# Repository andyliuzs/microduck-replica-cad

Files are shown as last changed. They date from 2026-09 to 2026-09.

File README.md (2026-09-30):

# Microduck 复刻 · SolidWorks 三维图纸与装配说明书

> **可编辑的 SolidWorks 源文件**（不是 STL），外加一份 21 页的装配安装说明书。**两个版本**：
> **v2.1 飞特 HD-1910 版**（2026-09-25，轮辋 + 轮胎合并）和 **v1.1 原版 XL330 版**（2026-09-15，踝 / 小腿 / 脚同步改了）。
> 配套主仓：[**fanhao375/microduck-replica**](https://github.com/fanhao375/microduck-replica) —— 整机复刻、电路板与逆向分析都在那边。

> **模型与打印文件统一在本仓库维护（2026-09-28）。** 主仓已移除旧上游 STL 下载副本。请先选择飞特或 XL330 版本，再核对具体附件；两款舵机的配合件不能混用。

> 📦 **压缩包在 [Releases 页](../../releases)（页面右边栏），不在上面的文件列表里。** 374 MB 的 SolidWorks 不适合塞进 git。
> 🖨️ 飞特打印工程见下方[打印说明](#打印)。仓库内 3MF 是 **2026-09-15 版，尚未包含 v2.1 的 TPU 合体轮胎**；该轮胎变更属于轮滑变体。[MakerWorld 工程](https://makerworld.com.cn/zh/models/2963569-microduck#profileId-3478428)由机械行者Robo 上传，本轮未核验其在线版本。

<div align="center">
  飞特 HD-1910 版装机实物
  <br><sub>2026-09-13 · 飞特 HD-1910 版装出来了，15 颗全在位</sub>
</div>

<div align="center">
  microduck 装配体
  microduck 爆炸图
</div>

---

## 两个版本，选一个下

| | 原版 · XL330 · **v1.1** | 飞特 · HD-1910 · **v2.1** |
|---|---|---|
| **舵机** | Dynamixel XL330-M288 | 飞特 HD-1910-C001 |
| **文件** | 57 个 SolidWorks，无后缀 | 60 个 SolidWorks + 11 个 STEP，`-FT` 后缀 |
| **差别** | — | **舵盘凸出**，8 个配合件改了（[改了什么](#飞特-hd-1910-版改了什么)） |
| **打印** | 从 [v1.1 SolidWorks 源文件](https://github.com/fanhao375/microduck-replica-cad/releases/tag/v1.1) 按零件导出 STL 后切片；本仓暂无该版整套打印工程 | [`打印/` 3MF](打印/) 为 09-15 版，未含 v2.1 合体轮胎；见[版本提示](#打印) |
| **实物** | — | 已装出（上图） |
| **下载** | [`SolidWorks-XL330-v1.1.zip`](https://github.com/fanhao375/microduck-replica-cad/releases/download/v1.1/SolidWorks-XL330-v1.1.zip) 333 MB | [`SolidWorks-FT2026-09-25.zip`](https://github.com/fanhao375/microduck-replica-cad/releases/download/v2.1/SolidWorks-FT2026-09-25.zip) 343 MB |

两版的踝 / 小腿 / 脚在 2026-09-15 同步成了一套设计；装配说明书和组件图两版通用。

---

## 图纸作者：机械行者Robo

**这套三维图纸和安装说明书，全部由「机械行者Robo」建模、整理、编写。**

他还在做装配视频，有装配上的问题去他那儿留言最快：

<table>
<tr>
<td align="center" width="50%">
  小红书 机械行者Robo<br>
  <b>小红书 · 机械行者Robo</b><br>
  <sub>小红书号 270594280</sub>
</td>
<td align="center" width="50%">
  抖音 机械行者Robo<br>
  <b>抖音 · 机械行者Robo</b><br>
  <sub>抖音号 1852366168 —— 「人人可做机器人」</sub>
</td>
</tr>
</table>

> 觉得图纸有用的话，去关注一下他 —— 这套东西建模和整理的工作量不小，而且是免费放出来的。

---

## 下载

| 要什么 | 在哪 |
|---|---|
| **飞特 HD-1910 版源文件**（v2.1 · 60 个 SolidWorks，解压约 358 MB） | 👉 [**下载 `SolidWorks-FT2026-09-25.zip`**](https://github.com/fanhao375/microduck-replica-cad/releases/download/v2.1/SolidWorks-FT2026-09-25.zip) |
| **只要改动件的 STEP**（v2.1 · 11 个） | 👉 [**下载 `STEP-changed-parts-FT-2026-09-30.zip`**](https://github.com/fanhao375/microduck-replica-cad/releases/download/v2.1/STEP-changed-parts-FT-2026-09-30.zip) —— 新增面部零件 FT1（适配瑞莎原版摄像头），不用 SolidWorks 也能开 |
| **原版 XL330 版源文件**（v1.1 · 57 个 SolidWorks，解压 348 MB） | 👉 [**下载 `SolidWorks-XL330-v1.1.zip`**](https://github.com/fanhao375/microduck-replica-cad/releases/download/v1.1/SolidWorks-XL330-v1.1.zip)（[v1.0 旧版](../../releases/tag/v1.0) 仍可下） |
| **装配 BOM**（机械行者Robo 整理，33 个打印件 + 21 个外购件，含材料、数量、单价，**2026-09-29 起所有外购件都带淘宝 / 天猫采购链接**） | [`BOM/装配BOM-机械行者Robo-2026-09-29-带采购链接.xlsx`](BOM/装配BOM-机械行者Robo-2026-09-29-带采购链接.xlsx)，下面有校对过的表 |
| **装配安装说明书**（21 页 PDF） | [`安装说明书/microduck装配安装说明书.pdf`](安装说明书/microduck装配安装说明书.pdf) |
| **组件图 / 爆炸图**（23 张） | [`组件图/`](组件图/) |
| 🖨️ **打印工程文件**（Bambu Studio `.3mf`，4.9 MB，2026-09-15 版） | [`打印/microduck-飞特版-BambuStudio.3mf`](打印/microduck-飞特版-BambuStudio.3mf) —— 5 个盘、52 个对象；**未含 v2.1 合体轮胎**，材料与切片参数见[打印说明](#打印) |
| 🖨️ **MakerWorld 打印入口** | [MakerWorld · microduck 飞特版](https://makerworld.com.cn/zh/models/2963569-microduck#profileId-3478428) —— 使用前核对作者标注的版本与材料，本轮未核验在线更新 |

> **为什么源文件放 Releases 不放 git**：SolidWorks 是二进制格式，git 存它既不能 diff 也不能合并，
> 只会一版版往历史里堆 —— 改三次图仓库就上 1 GB，而且**历史删不掉**。
> 放 Release 附件则不计入仓库体积，更新时发新版即可，clone 这个仓库始终只有几 MB。

---

## 飞特 HD-1910 版改了什么

原版用 Dynamixel XL330，本仓库主仓走飞特 HD-1910（更便宜、力矩大 2.5 倍、电压额定匹配 —— 见[主仓执行器选型](https://github.com/fanhao375/microduck-replica/blob/master/docs/执行器选型.md)）。
**两款舵机外形接近但舵盘不一样：HD-1910 的舵盘是凸出来的，XL330 是凹进去的。** 所有跟舵盘配合的件都得改：

| 改动件 | 为什么 |
|---|---|
| `left_upper_leg` / `right_upper_leg` 左右上腿 | 髋 pitch 和膝的舵盘位 |
| `leg` 小腿 | 膝和踝的舵盘位 |
| `trunk_base` 躯干底座 | 髋 yaw 舵机安装位 |
| `yaw2roll` 偏航转横滚 | 髋 yaw 舵盘 → 髋 roll 舵机 |
| `bearing_roll` 轴承滚轮 | 髋 roll 轴承座 |
| `01-upper_leg_rigidity_plate` 上腿加固板 | 跟上腿一起改 |
| `99-yaw_roll_motion` 偏航横滚运动 | 头部 yaw/roll，`-F` 和 `-FT` 两个变体 |

**文件命名**：所有件带 `-FT` 后缀（FT = 飞特）。没改的件也带 `-FT`，是为了整套装配体引用一致 —— 27 个件跟 v1.0 内容一样，只是改了名。

**多出来的**：`HD-1910-c001-dan / -shuang`（单盘 / 双盘舵机模型）、`舵机比较.SLDASM`（两款舵机并排对比）、`飞特电机资料1/`（飞特给的 STEP / DWG / 规格图）。

⚠️ 装配说明书 PDF 和组件图**还是 v1.0 的**，装配顺序和步骤不变，只是舵机换了。

---

## 飞特 v2.1 改了什么（2026-09-25）

- **`rim_轮辋` 和 `tire_轮胎` 合并为 `合体轮胎`**：两个独立件组装困难，删除后合成一个「合体轮胎」，材料 **TPU**。
- 全套 SolidWorks 现在是 **60 个**（17 装配体 + 43 零件）；改动件 STEP 增到 **10 个**（新增 `合体轮胎.STEP`）。

---

## 面部零件适配瑞莎原版摄像头（2026-09-30）

- **`face_part_面部零件` 新增 `-FT1` 变体**：把摄像头安装孔距改成能直接装**瑞莎（Radxa）原版摄像头**。
- 改动件 STEP 包相应新增 **`face_part_面部零件-FT1适配瑞莎原版摄像头 改了孔距.STEP`**，由 10 个增到 **11 个**。

---

## XL330 原版 v1.1 改了什么（2026-09-15）

飞特版改踝、小腿、脚那一片时顺手把原版也改了，两版这一区域现在是同一套设计：

```
改了   05_左小腿 · 06_左踝脚 · 14_右小腿 · 15_右踝脚 · 10_头部总成
       ankle_left 脚踝左 · foot_left 左脚 · leg 腿部
新增   deep groove ball bearings gb（轴承模型）
改名   00-microduck装配体 → 00-microduck装配体 XL330-288舵机版本
       ankle_right_脚踝右 → ankle_right脚踝右
```

46 个件跟 v1.0 一样。

---

## 装配 BOM

> 工作簿已更新到 **2026-09-29**：轮辋 + 轮胎合并为**合体轮胎**（打印件 33 项），外购件扩到 **21 项**，并且**所有外购件都加了淘宝 / 天猫采购链接**（2026-09-16 版只有轴承和螺丝有）。

[`BOM/装配BOM-机械行者Robo-2026-09-29-带采购链接.xlsx`](BOM/装配BOM-机械行者Robo-2026-09-29-带采购链接.xlsx) 是机械行者Robo 按装配体整理的。2026-09-29 版把外购件补齐成完整清单（主控 Radxa Zero 3W、TF 卡、飞特 URT2 调试板、电池座、ToF 等），并给每一项加上实际下单的淘宝 / 天猫链接（打板件指到主仓 github，拼团的直接标拼团）。电子件型号按主仓查证过的事实排（电池 NP-F550、舵机 15、`imu_to_dxl` 1），下面这张表照它排。有几处跟表不同：

| 表里 | 这里 | 依据 |
|---|---|---|
| 合体轮胎 / 滚轮叶片 | 标为**轮滑变体，走路不用** | 上游 `变体-轮滑/`，只有做轮滑功能才打 |
| 合体轮胎材料写 PLA | 实际应打 **TPU** | v2.1 合体轮胎是 TPU 软料，见[飞特 v2.1 改了什么](#飞特-v21-改了什么2026-09-25) |

### 一、3D 打印件（33 项）

| # | 零件 | 文件 | 材料 | 数量 | 备注 |
|---|---|---|---|---|---|
| 1 | 头部上壳 | `top_head_shell` | PLA | 1 | |
| 2 | 头部下壳 | `bottom_head_shell` | PLA | 1 | |
| 3 | 面部零件 | `face_part` | PLA | 1 | |
| 4 | 下巴 | `jaw` | PLA | 1 | |
| 5 | 软下巴 | `jaw_soft` | **TPU** | 1 | 软性件 |
| 6 | 软嘴顶部 | `soft_mouth_top` | **TPU** | 1 | 软性件 |
| 7 | 眼睛 | `noenoeil` | PLA | 1 | |
| 8 | 颈部 | `neck` | PLA | 2 | 可换铝合金增强 |
| 9 | 颈部俯仰 | `neck_pitch` | PLA | 1 | |
| 10 | 躯干底座 | `trunk_base` | PLA | 1 | 可换铝合金增强 |
| 11 | 左壳 | `left_shell` | PLA | 1 | |
| 12 | 右壳 | `right_shell` | PLA | 1 | |
| 13 | 髋部左 | `hip_l` | PLA | 2 | |
| 14 | 偏航转横滚 | `yaw2roll` | PLA | 1 | |
| 15 | 偏航横滚运动 | `yaw_roll_motion` | PLA | 1 | |
| 16 | 腿部 | `leg` | PLA | 2 | |
| 17 | 左上腿 | `left_upper_leg` | PLA | 1 | |
| 18 | 右上腿 | `right_upper_leg` | PLA | 1 | |
| 19 | 上腿加固板 | `upper_leg_rigidity_plate` | PLA | 2 | 可换铝合金增强 |
| 20 | 左脚 | `foot_left` | PLA | 1 | |
| 21 | 右脚 | `foot_right` | PLA | 1 | |
| 22 | 左脚底 | `sole_left` | PLA | 1 | |
| 23 | 右脚底 | `sole_right` | PLA | 1 | |
| 24 | 脚踝左 | `ankle_left` | PLA | 1 | |
| 25 | 脚踝右 | `ankle_right` | PLA | 1 | |
| 26 | 脚踝左 V1 | `ankle_l_v1` | PLA | 1 | 备选，与 24 二选一 |
| 27 | 脚踝右 V1 | `ankle_r_v1` | PLA | 1 | 备选，与 25 二选一 |
| 28 | 合体轮胎 | `合体轮胎` | **TPU** | 4 | **轮滑变体，走路不用**；v2.1 把轮辋 + 轮胎合并 |
| 29 | 滚轮叶片 | `roller_blade` | PLA | 2 | **轮滑变体，走路不用** |
| 30 | 电机支架 | `motor_support` | PLA | 1 | |
| 31 | 电源支架 | `power_support` | PLA | 1 | |
| 32 | 香蕉形 PCB 锁扣 | `banana_pcb_locker` | PLA | 1 | |
| 33 | 轴承滚轮 | `bearing_roll` | PLA | 2 | 可换铝合金增强 |

### 二、外购件（21 项）

| # | 件 | 数量 | 单价(元) | 备注 / 采购链接 |
|---|---|---|---|---|
| 34 | Radxa Zero 3W 主控 | 1 | 309 | [淘宝 763812025816](https://item.taobao.com/item.htm?id=763812025816) |
| 35 | 64GB TF 卡 | 1 | 60 | |
| 36 | RPI Robot HAT 电路板 | 1 | — | 官方开源，嘉立创打样；或[不打 HAT 飞线](https://github.com/fanhao375/microduck-replica/blob/master/docs/不打HAT.md) |
| 37 | imu_to_dxl 电路板 | 1 | — | 主仓自绘，[hardware/imu_to_dxl](https://github.com/fanhao375/microduck-replica/tree/master/hardware/imu_to_dxl) |
| 38 | 飞特 HD1901M 舵机 | 15 | — | 可[拼团](https://github.com/fanhao375/microduck-replica)；主仓写 **HD-1910-C001** |
| 39 | 飞特舵机 URT2 调试板 | 1 | 45 | [淘宝 575365901461](https://item.taobao.com/item.htm?id=575365901461&skuId=5435424470243) |
| 40 | NP-F550 电池 | 1 | 17 | 2S；[天猫 658975825526](https://detail.tmall.com/item.htm?id=658975825526&skuId=4925738602652) |
| 41 | 电池座 | 1 | 83 | [天猫 714898043960](https://detail.tmall.com/item.htm?id=714898043960&skuId=5173334659309) |
| 42 | 2.5mm 香蕉插头 PCB 铜镀金 | 2 | 1.6 | [淘宝 1066300439603](https://item.taobao.com/item.htm?id=1066300439603&skuId=6116801109787) |
| 43 | banana PCB | 1 | — | 嘉立创 |
| 44 | IMX219 摄像头模块 | 1 | 46.8 | [天猫 775872575316](https://detail.tmall.com/item.htm?id=775872575316) |
| 45 | VL53L8CX ToF 模块 | 1 | 49.5 | [淘宝 737603917521](https://item.taobao.com/item.htm?id=737603917521&skuId=5090650052053) |
| 46 | 扬声器 | 1 | 3.8 | 走 HAT 音频才要；[淘宝 902489608878](https://item.taobao.com/item.htm?id=902489608878&skuId=5925223242747) |
| 47 | 轴承 10×15×3 | 3 | 2.8 | [淘宝 670727787832](https://item.taobao.com/item.htm?id=670727787832) |
| 48 | 轴承 16×22×4 | 11 | 3.5 | [淘宝 539024647147](https://item.taobao.com/item.htm?id=539024647147&skuId=5716548727712) |
| 49 | 轴承 6×12×3 | 4 | 0.88 | 轮滑变体用，走路不用买；[淘宝 963037239628](https://item.taobao.com/item.htm?id=963037239628&skuId=6068333830994) |
| 50 | 螺丝 M2×5 | 1 包 | 3.05 | [天猫 637524754721](https://detail.tmall.com/item.htm?id=637524754721&skuId=5802482233046) |
| 51 | 螺丝 M2×6 | 1 包 | 4.05 | 同一家：[天猫 637524754721](https://detail.tmall.com/item.htm?id=637524754721&skuId=5802482233047) |
| 52 | 螺丝 M2.5×6 | 1 包 | 3.93 | 同一家：[天猫 637524754721](https://detail.tmall.com/item.htm?id=637524754721&skuId=6180818899668) |
| 53 | 螺丝 M2.5×8 | 1 包 | 2.08 | 同一家：[天猫 637524754721](https://detail.tmall.com/item.htm?id=637524754721&skuId=4572694449141) |
| 54 | 乐泰螺纹胶 243 | 1 | 9 | [淘宝 1056442610986](https://item.taobao.com/item.htm?id=1056442610986&skuId=6099342537028) |

> 每种螺丝多少颗见[主仓紧固件反推](https://github.com/fanhao375/microduck-replica/blob/master/docs/紧固件反推.md)。BOM 合计 **约 828 元**（不含 15 个舵机、HAT 板和 IMU 板；单价为机械行者Robo 下单时价）。

---

## 项目成本与开源倡议

> 🦆 **人人都可以拥有属于自己的 MicroDuck！**

**💰 项目成本**：除 15 个舵机、HAT 板和 IMU 板外，其余硬件成本约为 **828 元**。舵机、HAT 板和 IMU 板可以通过 [GitHub 项目](https://github.com/fanhao375/microduck-replica) 参与拼团，也可以根据需求在嘉立创、淘宝等平台自行购买。

后续还会陆续开源安装教程、调试教程，帮助大家更方便地完成 MicroDuck 的组装与调试。

**🤖 为什么要开源？** 希望让更多人能以更低的成本接触和学习具身智能、机器人控制与强化学习，动手实践、从零探索。如果这个项目对你有帮助，点个赞就是对我们最大的支持 ❤️，也欢迎点个 Star ⭐！

> 🔗 GitHub：https://github.com/fanhao375/microduck-replica
> 📕 小红书：机械行者 · 🎵 抖音：机械行者Robo · B站：机械行者Robo

---

## 打印

**[`打印/microduck-飞特版-BambuStudio.3mf`](打印/microduck-飞特版-BambuStudio.3mf)** —— 机械行者Robo 排好盘的 Bambu Studio 工程，版本为 **2026-09-15**。

**这不是完整 v2.1 打印包。** 已核对工程内仍有独立轮辋 4 个、轮胎 4 个，没有 v2.1 合体轮胎；若制作新版轮滑变体，请从 [v2.1 源文件](https://github.com/fanhao375/microduck-replica-cad/releases/tag/v2.1) 导出合体轮胎，按 TPU 切片，避免与旧轮辋/轮胎重复打印。[MakerWorld 在线工程](https://makerworld.com.cn/zh/models/2963569-microduck#profileId-3478428)是否同步本轮未验证。此处只更新入口与版本说明，没有修改 3MF 或 CAD 模型。

| 项 | 值 |
|---|---|
| 打印机 | Bambu Lab **P2S**，0.4 喷嘴 |
| 耗材 | PLA Basic |
| 层高 | 0.2 mm |
| 盘数 | **5 盘**，52 个对象 —— 09-15 工程中的对象，非 v2.1 完整清单 |

<table>
<tr>
<td align="center"><br><sub>盘 1</sub></td>
<td align="center"><br><sub>盘 2</sub></td>
<td align="center"><br><sub>盘 3</sub></td>
<td align="center"><br><sub>盘 4</sub></td>
<td align="center"><br><sub>盘 5</sub></td>
</tr>
</table>

**怎么用**：先核对舵机版本、所需零件与材料，再用 Bambu Studio 打开工程、检查排盘并切片。软下巴、软嘴顶部与轮胎等柔性件应按 BOM 使用 TPU，不能统一按默认 PLA 打印。使用其他打印机时，应确认切片软件支持导入该 3MF，并按自己的机器重设打印参数。

耗材、螺丝、热熔螺母的采购在[主仓机械采购清单](https://github.com/fanhao375/microduck-replica/blob/master/docs/机械采购清单.md)。

---

## 组件清单（15 个）

| 序号 | 组件 | 英文 | 位置 / 功能 |
|---|---|---|---|
| 01 | 躯干主体 | Torso | 机身主体，**全部组件的装配基准件**，承载左/右腿、颈部与控制器 |
| 02 | 左髋 | Left Hip | 左腿根部髋关节（Pitch），腿部前后摆动 |
| 03 | 左髋 Roll | Left Hip Roll | 左腿髋部横滚关节，腿部侧向摆动 |
| 04 | 左大腿 | Left Thigh | 连接髋关节与小腿 |
| 05 | 左小腿 | Left Calf | 连接大腿与踝关节 |
| 06 | 左踝脚 | Left Ankle & Foot | 踝关节及脚部，足部转动与支撑 |
| 07 | 颈根 | Neck Base | 颈部与机身连接处的旋转底座（Yaw） |
| 08 | 颈俯仰 | Neck Pitch | 颈部俯仰摆动关节 |
| 09 | 头 Yaw / Roll | Head Yaw / Roll | 头部水平摆动与横滚关节 |
| 10 | 头部总成 | Head Assembly | 头部完整组件，含外壳、摄像头等 |
| 11 | 右髋 | Right Hip | 与 02 镜像对称 |
| 12 | 右髋 Roll | Right Hip Roll | 与 03 镜像对称 |
| 13 | 右大腿 | Right Thigh | 与 04 镜像对称 |
| 14 | 右小腿 | Right Calf | 与 05 镜像对称 |
| 15 | 右踝脚 | Right Ankle & Foot | 与 06 镜像对称 |

## 装配顺序

**按编号 01 → 15 依次装，就是推荐的整机装配顺序：**

```
1.  01           躯干主体 —— 作为整机基准先行固定
2.  02 → 06      左腿   左髋 → 左髋Roll → 左大腿 → 左小腿 → 左踝脚
3.  07 → 10      颈头   颈根 → 颈俯仰 → 头Yaw/Roll → 头部总成
4.  11 → 15      右腿   右髋 → 右髋Roll → 右大腿 → 右小腿 → 右踝脚
```

**每一步的详细步骤、配图和注意事项，见** [装配安装说明书 PDF](安装说明书/microduck装配安装说明书.pdf)。

---

## 组件图

<table>
<tr>
<td align="center"><br><sub><b>01</b> 躯干主体</sub></td>
<td align="center"><br><sub><b>02</b> 左髋</sub></td>
<td align="center"><br><sub><b>03</b> 左髋 Roll</sub></td>
<td align="center"><br><sub><b>04</b> 左大腿</sub></td>
</tr>
<tr>
<td align="center"><br><sub><b>05</b> 左小腿</sub></td>
<td align="center"><br><sub><b>06</b> 左踝脚</sub></td>
<td align="center"><br><sub><b>07</b> 颈根</sub></td>
<td align="center"><br><sub><b>08</b> 颈俯仰</sub></td>
</tr>
<tr>
<td align="center"><br><sub><b>09</b> 头 Yaw/Roll</sub></td>
<td align="center"><br><sub><b>10</b> 头部总成</sub></td>
<td align="center"><br><sub><b>11</b> 右髋</sub></td>
<td align="center"><br><sub><b>12</b> 右髋 Roll</sub></td>
</tr>
<tr>
<td align="center"><br><sub><b>13</b> 右大腿</sub></td>
<td align="center"><br><sub><b>14</b> 右小腿</sub></td>
<td align="center"><br><sub><b>15</b> 右踝脚</sub></td>
<td align="center"><br><sub>头部总成（爆炸）</sub></td>
</tr>
</table>

<div align="center">
  零件总览<br>
  <sub>全部零件总览</sub>
</div>

---

## 文件清单

### 装配体（16 个 `.SLDASM`）

`00-microduck装配体` 是总装，下面 15 个是分组件：

```
00-microduck装配体      70.3 MB      08_颈俯仰               0.3 MB
01_躯干主体             20.5 MB      09_头yaw-roll          0.7 MB
02_左髋yaw-roll         2.5 MB      10_头部总成             22.2 MB
03_左髋roll             3.8 MB      11_右髋yaw-roll         2.5 MB
04_左大腿               1.9 MB      12_右髋roll             3.8 MB
05_左小腿               1.9 MB      13_右大腿               2.0 MB
06_左踝脚               9.3 MB      14_右小腿               1.8 MB
07_颈根                 0.1 MB      15_右踝脚               9.3 MB
```

### 零件（40 个 `.SLDPRT`）

| 类别 | 零件 |
|---|---|
| **躯干 / 外壳** | `trunk_base_躯干底座` · `left_shell_左壳` · `right_shell_右壳` · `power_support_电源支架` · `banana_pcb_locker_香蕉形PCB锁扣` |
| **腿** | `leg_腿部` · `left_upper_leg_左上腿` · `right_upper_leg_右上腿` · `hip_l_髋部左` · `yaw2roll_偏航转横滚` · `yaw_roll_motion_偏航横滚运动` · `01-upper_leg_rigidity_plate_上腿加固板` |
| **踝 / 脚** | `ankle_left_脚踝左` · `ankle_right_脚踝右` · `foot_left_左脚` · `foot_right_右脚` · `sole_left_左脚底` · `sole_right_右脚底` |
| **颈 / 头** | `neck_颈部` · `neck_pitch_颈部俯仰` · `top_head_shell_头部上壳` · `bottom_head_shell_头部下壳` · `face_part_面部零件` · `jaw_下巴` · `jaw_soft_软下巴` · `soft_mouth_top_软嘴顶部` · `noenoeil_眼睛` |
| **摄像头** | `m12_lens_holder_M12镜头座` · `lens_镜头` |
| **电路板** | `3D_PCB1_2026-09-08`（imu_to_dxl，2026-09-08 版）· `elec_rpi_robot_hat_pcb_树莓派机器人HAT电路板` · `pcb__raspberry_pi_zero_2_w_树莓派Zero2W电路板` |
| **标准件 / 外购** | `舵机xl330-288` · `xl330-m288-t1` · `xl330-m288-t2` · `轴承16×22×4` · `bearing_roll_轴承滚轮` · `M2铜柱` · `motor_support_电机支架` · `np_f970_NPF970电池` |

### 两处命名要留意

- **`np_f970_NPF970电池`** —— 文件名沿用了上游的 `np_f970`，但**实物是 NP-F550**。
  主仓实测上游网格包围盒为 **70.8 × 38.6 × 20.6 mm**，正是 F550/F570 的尺寸；真 NP-F970 厚约 60 mm，
  **买错装不进去，而且 300 g 会吃掉整机预算的三分之一**。详见
  [主仓 BOM 的电池型号勘误](https://github.com/fanhao375/microduck-replica/blob/master/BOM.md)。
- **`pcb__raspberry_pi_zero_2_w`** —— 同样是上游的占位命名，**实机主控是 Radxa Zero 3W**（RK3566），
  只是外形同为 Pi Zero。见[主仓的硬件方案逆向](https://github.com/fanhao375/microduck-replica/blob/master/docs/硬件方案逆向.md)。

---

## 通用注意事项（摘自说明书）

- 装配前对照 BOM 清点零件数量与规格，确认 **M2 / M2.5** 螺丝与紧固件齐全
- **舵机类关节件：装配前先通电归中位再锁紧**，避免行程偏移
- 螺丝**对角分步预紧**，避免单边受力导致零件变形；塑料件切勿过度锁紧
- **左右对称件（髋 / 大腿 / 小腿 / 踝脚）务必区分左右**，切勿装反
- 线缆统一固定、预留关节活动余量，严禁压线、夹线、缠绕
- 每完成一个活动关节，转动测试一次，检查是否干涉、卡滞、异响
- 首次通电前检查所有电气连接、绝缘与极性

**推荐工具**：十字/内六角螺丝刀 · 镊子 · 螺纹胶 · 舵机中位调试工具或控制板。

---

## 声明与许可

> ⚠️ **这是第三方复刻件，不是官方设计。** 与 Pollen Robotics 无隶属关系，未获其背书。

本套图纸依据 [`pollen-robotics/microduck_rl`](https://github.com/pollen-robotics/microduck_rl) 公开发布的
STL 网格重建为可编辑的 SolidWorks 参数模型。上游 3D 模型许可为 **CC BY-NC-SA**，
因此本仓库的图纸作为衍生作品同样以 **[CC BY-NC-SA 4.0](https://creativecommons.org/licenses/by-nc-sa/4.0/deed.zh)** 发布：
**署名 · 非商业性使用 · 相同方式共享**。

- **图纸与说明书著作权归「机械行者Robo」**，转载与二次分发请保留署名
- 文档文字部分同样按 CC BY-NC-SA 4.0 发布
- Microduck 是 Pollen Robotics 的商业产品，本仓库不提供任何官方支持

**发现问题**请开 [issue](../../issues)，或到上面两个账号留言。

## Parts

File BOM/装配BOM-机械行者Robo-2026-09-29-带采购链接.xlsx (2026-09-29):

序号 | 类别 | 名称 | 原文件名 | 材料 |  | 数量 | 单价 | 总格 | 网址
一、3D打印件（需打印）
1 | 3D打印件 | 头部上壳 | top_head_shell_头部上壳.stp | PLA |  | 1 |  | 139 | https://item.taobao.com/item.htm?from=cart&id=1083122166800&skuId=6306393642451&upStreamPrice=13900
2 | 3D打印件 | 头部下壳 | bottom_head_shell_头部下壳.stp | PLA |  | 1
3 | 3D打印件 | 面部零件 | face_part_面部零件.stp | PLA |  | 1
4 | 3D打印件 | 下巴 | jaw_下巴.stp | PLA |  | 1
5 | 3D打印件 | 软下巴 | jaw_soft_软下巴.stp | PLA | 建议改用TPU软料 | 1
6 | 3D打印件 | 软嘴顶部 | soft_mouth_top_软嘴顶部.stp | PLA | 建议改用TPU软料 | 1
7 | 3D打印件 | 眼睛 | noenoeil_眼睛.stp | PLA |  | 1
8 | 3D打印件 | 颈部 | neck_颈部.stp | PLA | 建议铝合金 | 2
9 | 3D打印件 | 颈部俯仰 | neck_pitch_颈部俯仰.stp | PLA |  | 1
10 | 3D打印件 | 躯干底座 | trunk_base_躯干底座.stp | PLA | 建议铝合金 | 1
11 | 3D打印件 | 左壳 | left_shell_左壳.stp | PLA |  | 1
12 | 3D打印件 | 右壳 | right_shell_右壳.stp | PLA |  | 1
13 | 3D打印件 | 髋部左 | hip_l_髋部左.stp | PLA |  | 2
14 | 3D打印件 | 偏航转横滚 | yaw2roll_偏航转横滚.stp | PLA |  | 1
15 | 3D打印件 | 偏航横滚运动 | yaw_roll_motion_偏航横滚运动.stp | PLA |  | 1
16 | 3D打印件 | 腿部 | leg_腿部.stp | PLA |  | 2
17 | 3D打印件 | 左上腿 | left_upper_leg_左上腿.stp | PLA |  | 1
18 | 3D打印件 | 右上腿 | right_upper_leg_右上腿.stp | PLA |  | 1
19 | 3D打印件 | 上腿加固板 | upper_leg_rigidity_plate_上腿加固板.stp | PLA | 建议铝合金 | 2
20 | 3D打印件 | 左脚 | foot_left_左脚.stp | PLA |  | 1
21 | 3D打印件 | 右脚 | foot_right_右脚.stp | PLA |  | 1
22 | 3D打印件 | 左脚底 | sole_left_左脚底.stp | PLA |  | 1
23 | 3D打印件 | 右脚底 | sole_right_右脚底.stp | PLA |  | 1
24 | 3D打印件 | 脚踝左 | ankle_left_脚踝左.stp | PLA |  | 1
25 | 3D打印件 | 脚踝右 | ankle_right_脚踝右.stp | PLA |  | 1
26 | 3D打印件 | 脚踝左(V1备选) | ankle_l_v1_脚踝左V1.stp | PLA |  | 1
27 | 3D打印件 | 脚踝右(V1备选) | ankle_r_v1_脚踝右V1.stp | PLA |  | 1
28 | 3D打印件 | 合体轮胎 | 合体轮胎.stp | PLA |  | 4
29 | 3D打印件 | 滚轮叶片 | roller_blade_滚轮叶片.stp | PLA |  | 2
30 | 3D打印件 | 电机支架 | motor_support_电机支架.stp | PLA |  | 1
31 | 3D打印件 | 电源支架 | power_support_电源支架.stp | PLA |  | 1
32 | 3D打印件 | 香蕉形PCB锁扣 | banana_pcb_locker_香蕉形PCB锁扣.stp | PLA |  | 1
33 | 3D打印件 | 轴承滚轮 | bearing_roll_轴承滚轮.stp | PLA | 建议铝合金 | 2
二、外购标准件（无需打印） |  |  |  |  |  |  |  | 0 | 网址
1 | 外购件 | Radxa Zero 3W 主控板 |  | 电子件 |  | 1 | 309 | 309 | https://item.taobao.com/item.htm?id=763812025816&last_time=1790655696&upStreamPrice=88800
2 | 外购件 | 64GB TF 卡 |  | 电子件 |  | 1 | 60 | 60
3 | 外购件 | 树莓派机器人HAT电路板 |  | 电子件 | 可拼团 github | 1 | / | 0 | https://github.com/fanhao375/microduck-replica
4 | 外购件 | imu_to_dxl电路板 |  | 电子件 | 可拼团github | 1 | / | 0 | https://github.com/fanhao375/microduck-replica
5 | 外购件 | 飞特HD1901M舵机 |  | 电子件 | 可拼团github | 15 | / | 0 | https://github.com/fanhao375/microduck-replica
6 | 外购件 | 飞特舵机URT2调试板 |  | 电子件 |  | 1 | 45 | 45 | https://item.taobao.com/item.htm?id=575365901461&xxc=shop&from=cart&skuId=5435424470243
7 | 外购件 | NP-F550电池 |  | 电子件 |  | 1 | 17 | 17 | https://detail.tmall.com/item.htm?id=658975825526&skuId=4925738602652
8 | 外购件 | 电池座 |  | 电子件 |  | 1 | 83 | 83 | https://detail.tmall.com/item.htm?id=714898043960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
9 | 外购件 | 2.5mm香蕉插头PCB铜镀金 |  | 电子件 |  | 2 | 1.6 | 3.2 | https://item.taobao.com/item.htm?from=cart&id=1066300439603&skuId=6116801109787&upStreamPrice=160
10 | 外购件 | banana PCB |  | 电子件 |  | 1 | / | 0 | 嘉立创
11 | 外购件 | IMX219摄像头模块 |  | 光学件 |  | 1 | 46.8 | 46.8 | https://detail.tmall.com/item.htm?id=775872575316
12 | 外购件 | VL53L8CX ToF 模块 |  | 电子件 |  | 1 | 49.5 | 49.5 | https://item.taobao.com/item.htm?from=cart&id=737603917521&skuId=5090650052053&upStreamPrice=4950
13 | 外购件 | 扬声器 |  | 电子件 |  | 1 | 3.8 | 3.8 | https://item.taobao.com/item.htm?ali_trackid=318_1fb351596f290624d1f838f6933a4bf9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
14 | 外购件 | 轴承 10×15×3 |  | 标准件 |  | 3 | 2.8 | 8.4 | https://item.taobao.com/item.htm?id=670727787832
15 | 外购件 | 轴承 16×22×4 |  | 标准件 |  | 11 | 3.5 | 38.5 | https://item.taobao.com/item.htm?id=539024647147&skuId=5716548727712
16 | 外购件 | 轴承 6×12×3 | 轮滑鞋用轴承 | 标准件 |  | 4 | 0.88 | 3.52 | https://item.taobao.com/item.htm?id=963037239628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
17 | 外购件 | 螺丝M2×5 |  | 标准件 |  | 1包 | 3.05 | 3.05 | https://detail.tmall.com/item.htm?ali_trackid=318_52a09f69533ca8994dc6d0b507aea17b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
18 | 外购件 | 螺丝M2×6 |  | 标准件 |  | 1包 | 4.05 | 4.05 | https://detail.tmall.com/item.htm?ali_trackid=318_52a09f69533ca8994dc6d0b507aea17b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
19 | 外购件 | 螺丝M2.5×6 |  | 标准件 |  | 1包 | 3.93 | 3.93 | https://detail.tmall.com/item.htm?ali_trackid=318_52a09f69533ca8994dc6d0b507aea17b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
20 | 外购件 | 螺丝M2.5×8 |  | 标准件 |  | 1包 | 2.08 | 2.08 | https://detail.tmall.com/item.htm?ali_trackid=318_52a09f69533ca8994dc6d0b507aea17b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
21 | 外购件 | 乐泰螺纹胶243 |  | 标准件 |  | 1 | 9 | 9 | https://item.taobao.com/item.htm?id=1056442610986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
合计：3D打印件 33 项 / 外购件 21项 |  |  |  |  |  |  |  | 828.83
说明： 🦆 人人都可以拥有属于自己的 MicroDuck！ 💰 项目成本说明 除 15 个舵机、HAT 板和 IMU 板 外，其余硬件成本约为 828 元。 15 个舵机、HAT 板和 IMU 板 可以通过 GitHub 项目参与拼团，也可以根据需求在 嘉立创、淘宝 等平台自行购买。 后续我们还会陆续开源 安装教程、调试教程，帮助大家更方便地完成 MicroDuck 的组装与调试。 🤖 为什么要开源？ 我们希望让更多人能够以更低的成本接触和学习 具身智能、机器人控制与强化学习。 人人都有属于自己的一只鸭子。 通过开源，我们希望和大家一起打造一个更加开放、友好的学习环境，让更多人能够动手实践，从零开始探索具身智能。 如果这个项目对你有所帮助，点个赞就是对我们最大的支持 ❤️ 也欢迎大家关注我们的 GitHub，帮忙点个 Star ⭐！ 🔗 GitHub： https://github.com/fanhao375/microduck-replica 📕 小红书：机械行者 🎵 抖音：机械行者Robo B站：机械行者Robo

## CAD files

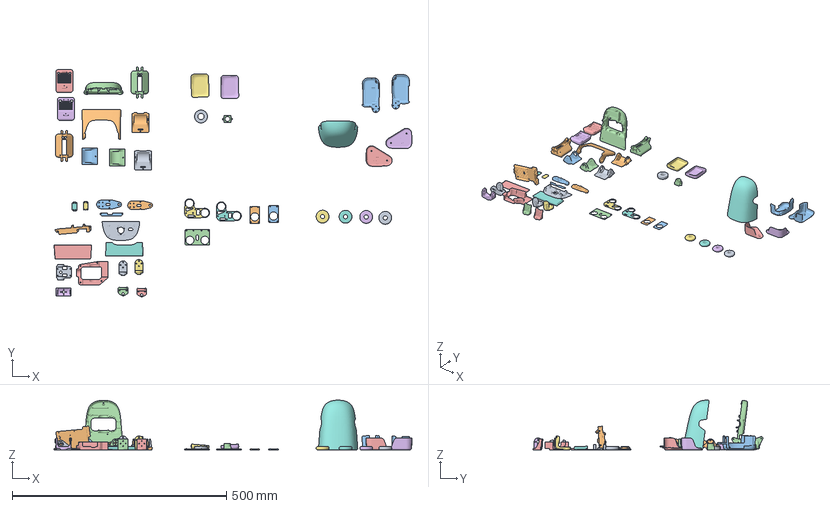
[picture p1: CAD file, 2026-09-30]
打印/microduck-飞特版-BambuStudio2026-09-30.3mf
835.9 x 536.9 x 116.0 mm
ankle_l_v1_脚踝左V1.stl
ankle_r_v1_脚踝右V1.stl
banana_pcb_locker_香蕉形PCB锁扣.stl
bottom_head_shell_头部下壳.stl
foot_left_左脚.stl
foot_right_右脚.stl
hip_l_髋部左.stl x 2
jaw_soft_软下巴.stl
jaw_下巴.stl
left_shell_左壳.stl
m12_lens_holder_M12镜头座.stl
motor_support_电机支架.stl
neck_pitch_颈部俯仰.stl
neck_颈部.stl x 2
noenoeil_眼睛.stl
power_support_电源支架.stl
right_shell_右壳.stl
roller_blade_滚轮叶片.stl x 2
soft_mouth_top_软嘴顶部.stl
sole_left_左脚底.stl
sole_right_右脚底.stl
top_head_shell_头部上壳.stl
face_part_面部零件.stp
ankle_right脚踝右.STEP
ankle_left_脚踝左.STEP
right_upper_leg_右上腿-FT.STEP
left_upper_leg_左上腿-FT.STEP
01-upper_leg_rigidity_plate_上腿加固板-FT.STEP x 2
99-yaw_roll_motion_偏航横滚运动-F.STEP
leg_腿部-FT.STEP x 2
trunk_base_躯干底座.stl

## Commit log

2026-09-25 飞特版 v2.1：轮辋+轮胎合并为合体轮胎（TPU），README 链接与说明同步更新
2026-09-28 Clarify centralized model downloads and print project versions
2026-09-29 装配BOM更新至09-29版（带采购链接），替换09-16版
    [装配BOM-机械行者Robo-2026-09-16-带采购链接.xlsx, 装配BOM-机械行者Robo-2026-09-29-带采购链接.xlsx]
2026-09-30 README 同步 09-29 装配 BOM：33 打印件 + 21 外购件（带采购链接），新增项目成本与开源倡议
2026-09-30 飞特版：面部零件 face_part 出 -FT1 变体，适配瑞莎原版摄像头（改孔距），改动件 STEP 增到 11 个
2026-09-30 README 对照表：飞特版改动件 STEP 由 10 个改为 11 个（含面部零件 FT1）
2026-09-30 飞特版打印工程更新至 09-30 版，替换旧版 3mf
    [microduck-飞特版-BambuStudio.3mf, microduck-飞特版-BambuStudio2026-09-30.3mf]
2026-10-12 README：加 B 站装配视频合集（分集目录）、B 站二维码，三个平台的账号都加上可点链接
2026-10-12 README：主控改为推荐 1G/2G 无 eMMC 版 + TF 卡，只走官方渠道
2026-10-20 飞特版 v2.2：头部上壳加散热孔，左右上腿减小间隙，README 链接与说明同步更新
2026-10-20 更新 BOM 和飞特版打印工程至 2026-10-20 版
    BOM 更新：
    - 增加防滑垫
    - 增加调试线
    - 完善螺丝采购链接
    3mf 文件更新：
    - 头部上壳增加散热孔
    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
2026-10-20 README：更新至 v2.2 版说明
    - 下载链接、打印工程、BOM 文件路径全部更新至 2026-10-20 版
    - 打印说明从 09-15 版改为 10-20 版（v2.2 散热孔 + 上腿间隙）
    - BOM 更新说明：增加防滑垫、调试线，完善螺丝采购链接
    - 对照表与下载表格备注加上 v2.2 变更说明
    - 顶部版本标题同步更新为「散热孔 + 上腿间隙 + BOM 更新」
2026-10-20 清理旧版文件：删除 09-29 BOM 和 09-30 打印工程
    - 删除 BOM/装配BOM-机械行者Robo-2026-09-29-带采购链接.xlsx
    - 删除 打印/microduck-飞特版-BambuStudio2026-09-30.3mf
    - 保留最新 2026-10-20 版本
2026-10-30 同步 10-20 3MF 工作副本（10-25 手动拉取的版本，补打比对基准）
